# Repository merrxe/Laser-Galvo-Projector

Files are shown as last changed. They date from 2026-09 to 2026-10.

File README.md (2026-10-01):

# Лазерный проектор векторной графики на базе архитектуры ILDAWaveX16

## Цель проекта
Создать лазерный проектор векторной графики на основе готовых гальванометров (20 Kpps) и микроконтроллера ESP32-S3 по открытой архитектуре **ILDAWaveX16**, способный отображать векторные изображения и анимации на вертикальной поверхности с частотой обновления не менее 20 000 точек в секунду. Устройство должно поддерживать воспроизведение файлов стандартного лазерного формата `.ild`.

## Функционал
- Максимальная скорость рисования: не менее 20 000 точек/сек (20 Kpps).
- Угловое разрешение: не хуже 0.01° (при 16‑битном ЦАП).
- Размер проекционной области на расстоянии 2 м: не менее 1×1 м.
- Мощность лазера: до 100 мВт (класс 3R) с возможностью модернизации до 500 мВт (класс 3B) при обязательном использовании защитных очков.
- Длина волны: 532 нм (зелёный).
- Поддерживаемые форматы: `.ild` (стандарт ILDA), потоковые координаты по сети.
- Режимы работы:
  - *Онлайн* – ПК (скрипт Python) стримит координаты по Wi-Fi/Ethernet.
  - *Автономный* – воспроизведение сцен напрямую с microSD‑карты памяти.

## Задачи проекта
1. Закупка компонентов: гальванометры 20 Kpps с драйверами, микроконтроллер ESP32‑S3, ЦАП DAC80508, лазерный модуль 532 нм с TTL, ОУ LM324, компоненты обвязки питания.
2. 3D‑моделирование в Rhino 8 и печать корпуса с посадочными местами (материал PETG/ABS).
3. Лазерная резка передней и задней панелей из акрила 3 мм.
4. Разработка электрической схемы: связь ESP32‑S3 с DAC80508 по шине SPI, аналоговый каскад на ОУ LM324 для преобразования сигналов ЦАП в дифференциальный сигнал ±5 В для драйверов гальванометров, TTL‑управление лазером, подключение microSD-слота по выделенной шине SPI.
5. Программирование ESP32‑S3 (C++, PlatformIO):
   - Приём пакетов по UDP (сетевые протоколы IDN / IWP) в кольцевой буфер.
   - Синхронная генерация сигналов X/Y через ЦАП по аппаратному таймеру.
   - Управление TTL‑гашением с компенсацией задержки зеркал.
   - Чтение, парсинг и воспроизведение файлов `.ild` с карты памяти для автономной работы.
6. Разработка ПО для ПК (Python):
   - Математическая генерация тестовых паттернов и фигур.
   - Потоковая трансляция кадров на проектор по сети в реальном времени.
7. Сборка, калибровка и тестирование: юстировка, калибровка по сетке с автоматическим расчётом поправочных коэффициентов (линейная коррекция и устранение подушкообразных искажений), определение предельной частоты сканирования.

## Безопасность
- Аппаратный сторожевой таймер (Watchdog) на ESP32‑S3 – принудительно отключает лазер через TTL при прекращении поступления координат или зависании сетевого стека.
- Защита при сбое сканаторов – цепь контроля, блокирующая лазер при падении питания гальванометров или остановке зеркал в одной точке.

## Элементная база
- **Гальванометры**: комплект 20Kpps Galvo Scanner (2 гальванометра с зеркалами, 2 платы драйверов, БП ±15В/24В).
- **Микроконтроллер**: ESP32‑S3 (Dual-Core, поддержка аппаратного SPI и Wi-Fi).
- **ЦАП**: DAC80508 (16 бит, 8 каналов, SPI).
- **Аналоговый тракт**: ОУ LM324 для сдвига уровней и формирования дифференциального сигнала ±5 В. Интегрированный DC-DC повышающий конвертер для аналогового питания ±8 В от USB-C.
- **Лазер**: модуль 532 нм, 100 мВт со встроенным драйвером и TTL‑входом.
- **Хранение данных**: встроенный слот microSD-карт (шина SPI).
- **Конструкция**: пластик PETG/ABS для печати шасси, прозрачный/чёрный акрил 3 мм для панелей.

## Заключение
Разрабатываемый лазерный проектор на базе архитектуры ILDAWaveX16 сочетает высокую разрядность (16 бит), производительность (от 20 000 точек/сек) и современные сетевые интерфейсы. Проект соответствует международным базовым стандартам лазерной индустрии (ILDA), что существенно повышает его научно-практическую ценность.

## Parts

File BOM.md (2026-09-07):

# Список закупок (BOM)

| № | Наименование | Кол-во | Примечание | Ссылка для заказа |
|---|---|---|---|---|
| 1 | Комплект гальванометров 20Kpps Galvo Scanner | 1 компл. | Включает 2 гальванометра с зеркалами, 2 платы драйверов, импульсный БП 24 В | |
| 2 | Микроконтроллер ESP32-DevKitC V4 (на базе NodeMCU-32S) | 1 шт. | | |
| 3 | ЦАП MCP4922 (12 бит, 2 канала, SPI) | 1 шт. | | |
| 4 | Сдвоенный ОУ TL082 | 1 шт. | Для сдвига уровней 0…4 В → ±5 В | |
| 5 | Инвертирующий преобразователь ICL7660 (или аналог) | 1 шт. | Для получения –12 В из +12 В | |
| 6 | Лазерный модуль 532 нм, 100 мВт с TTL-входом | 1 шт. | Класс 3R, возможность замены на 500 мВт (класс 3B) | |
| 7 | Блок питания 12 В / 3 А | 1 шт. | Для ESP32, лазера, вентилятора | |
| 8 | Блок питания 24 В (из комплекта гальванометров) | 1 шт. | Входит в п.1 | |
| 9 | Пластик PLA или PETG для 3D-печати | ~1 кг | Для шасси | |
| 10 | Акриловый лист 3 мм (прозрачный/чёрный) | ~300×300 мм | Для передней/задней панелей | |
| 11 | Вентилятор 40×40 мм, 12 В | 1 шт. | Активное охлаждение | |
| 12 | Резисторы 100 Ом | 4 шт. | Для защиты выходов TL082 | |
| 13 | Концевой выключатель (механическая блокировка) | 1 шт. | Разрыв цепи питания лазера при открытии корпуса | |
| 14 | Провода, разъёмы, панельки, винты, стойки | по необходимости | Расходные материалы для монтажа | |

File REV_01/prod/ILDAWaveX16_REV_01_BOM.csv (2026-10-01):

Designator | Qty | MPN | Comment | Manufacturer | Footprint | Datasheet | JLCPCB Part #
U8 | 1 | DAC80508MRTE | DAC80508 | Texas Instruments | WQFN | https://www.ti.com/lit/ds/symlink/dac80508.pdf | C2679529
U7 | 1 | EMIF06-MSD02N16 | EMIF06-MSD02N16 | STMicroelectronics | Micro QFN 3.5x1.2-16L | https://www.st.com/resource/en/datasheet/emif06-msd02n16.pdf | C5267594
U6 | 1 | TLV61048DBV | TLV61048 | Texas Instruments | SOT-23-6 | https://www.ti.com/lit/ds/symlink/tlv61048.pdf | C2861467
U5 | 1 | TPS62160DSG | TPS62160 | Texas Instruments | WSON-8 (2x2mm) | https://datasheet.lcsc.com/lcsc/1806070425_Texas-Instruments-TPS62162DSGR_C40256.pdf | C324077
U4 | 1 | NCP167BMX330TBG | NCP167BMX330TBG | onsemi | XDFN-4 | https://datasheet.lcsc.com/lcsc/2107280040_onsemi-NCP167BMX330TBG_C892227.pdf | C892227
U3 | 1 | LM324QT | LM324QT | STMicroelectronics | QFN16 3x3 | https://www.lcsc.com/datasheet/lcsc_datasheet_1810010620_STMicroelectronics-LM324QT_C183029.pdf | C183029
U2 | 1 | USBLC6-2P6 | USBLC6-2P6 | STMicroelectronics | SOT666 | https://www.st.com/resource/en/datasheet/usblc6-2.pdf | C15999
U1 | 1 | ESP32-S3-MINI-1 | ESP32-S3-MINI-1 | Espressif Systems | Module | https://www.espressif.com/sites/default/files/documentation/esp32-s3-mini-1_mini-1u_datasheet_en.pdf | C2913206
SW1,SW2 | 2 | PTS810SJG250SMTRLFS | PTS810 | C&K | 3.2x2.5mm SMD | https://datasheet.lcsc.com/lcsc/1810121629_C-K-PTS810SJG250SMTRLFS_C221895.pdf | C221895
R20,R27,R28,R29,R30,R31,R32,R33,R34,R35,R36 | 11 | AC0402FR-07150RL | 150R | Yageo | 0402 | https://eu.mouser.com/datasheet/2/447/PYu-AC_51_RoHS_L_7-1714230.pdf | C226790
R19 | 1 | HP03W5F100KT5E | 1R | UNI-ROYAL | 0603 | https://www.lcsc.com/datasheet/lcsc_datasheet_2304140030_UNI-ROYAL-Uniroyal-Elec-HP03W5F100KT5E_C2759448.pdf | C2759448
R18 | 1 | 0402WGF1003TCE | 100k | UNI-ROYAL(Uniroyal Elec) | 0402 | https://datasheet.lcsc.com/szlcsc/1810111814_UNI-ROYAL-Uniroyal-Elec-0402WGF1003TCE_C25741.pdf | C25741
R15 | 1 | AC0402FR-07100RL | 100R | Yageo | 0402 | https://eu.mouser.com/datasheet/2/447/PYu-AC_51_RoHS_L_7-1714230.pdf | C144808
R14 | 1 | RK73G1ETTP1004F | 1M | KOA Speer Elec | 0402 | https://datasheet.lcsc.com/szlcsc/2004171812_KOA-Speer-Elec-RK73G1ETTP1004F_C516088.pdf | C516088
R10,R13,R23,R24 | 4 | RC0402FR-0720KL | 20k | YAGEO | 0402 | https://www.lcsc.com/datasheet/lcsc_datasheet_2304140030_YAGEO-RC0402FR-0720KL_C93942.pdf | C93942
R7 | 1 | RC0402FR-078K2L | 8.2k | Yageo | 0402 | https://www.lcsc.com/datasheet/lcsc_datasheet_2304140030_YAGEO-RC0402FR-078K2L_C137929.pdf | C137929
R6 | 1 | RC0402FR-0743KL | 43k | Yageo | 0402 | https://www.lcsc.com/datasheet/lcsc_datasheet_2304140030_YAGEO-RC0402FR-0743KL_C185415.pdf | C185415
R4,R5 | 2 | RC0402JR-0727RL | 27R | YAGEO | 0402 | https://datasheet.lcsc.com/szlcsc/1810241322_YAGEO-RC0402JR-0727RL_C137890.pdf | C137890
R2,R3 | 2 | AC0402FR-075K1L | 5.1k | YAGEO | 0402 | https://datasheet.lcsc.com/szlcsc/1810241326_YAGEO-AC0402FR-075K1L_C144745.pdf | C144745
R1,R8,R9,R11,R12,R16,R17,R21,R22,R25,R26 | 11 | RC0402FR-7W10KL | 10k | YAGEO | 0402 | https://datasheet.lcsc.com/lcsc/2104091834_YAGEO-RC0402FR-7W10KL_C851848.pdf | C851848
Q1 | 1 | AP3404 | AP3404 | ALLPOWER(ShenZhen Quan Li Semiconductor) | SOT-23 | https://datasheet.lcsc.com/lcsc/2202132030_ALLPOWER-ShenZhen-Quan-Li-Semiconductor-AP3404_C2842665.pdf | C2842665
L3 | 1 | XAL4030-472 | 4.7uH | Coilcraft | 4.0x4.0x3.1 | https://www.coilcraft.com/getmedia/6adcb47d-8b55-416c-976e-1e22e0d2848c/xal4000.pdf | C19191688
L2 | 1 | MPZ1608B471ATA00 | 470R | TDK | 0603 | https://www.lcsc.com/datasheet/lcsc_datasheet_1811131653_TDK-MPZ1608B471ATA00_C114780.pdf | C114780
L1 | 1 | VLCF4020T-2R2N1R7 | 2.2uH | TDK | 4x4x2mm | https://datasheet.lcsc.com/szlcsc/1810211523_TDK-VLCF4020T-2R2N1R7_C136245.pdf | C136245
J13 | 1 | 473521001 | 473521001 | Molex | SMD | https://www.molex.com/content/dam/molex/molex-dot-com/products/automated/en-us/salesdrawingpdf/473/47352/473521001_sd.pdf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 | C293569
J6,J7,J8,J9,J10,J11,J12 | 7 | B2B-XH-A(LF)(SN) | J_JST-XH-B2B | JST Sales America | Through Hole, P=2.5mm | http://www.jst-mfg.com/product/pdf/eng/eXH.pdf | C158012
J3,J4,J5 | 3 | B3B-XH-A(LF)(SN) | J_JST-XH-B3B | JST Sales America | Through Hole, P=2.5mm | http://www.jst-mfg.com/product/pdf/eng/eXH.pdf | C144394
J2 | 1 | X0325FT7B2 | X0325FT7B2 | XKB Connection | 25P | https://www.lcsc.com/datasheet/lcsc_datasheet_2307171038_XKB-Connection-X0325FT7B2_C7464461.pdf | C7464461
J1 | 1 | TYPE-C-31-M-14 | TYPE-C-31-M-14 | Korean Hroparts Elec | 16pin USB C | https://www.usb.org/sites/default/files/documents/usb_type-c.zip | C223907
F1,F2,F3 | 3 | SMD0805-050-16V | 0.5A | TECHFUSE | 0805 | https://www.lcsc.com/datasheet/lcsc_datasheet_2105241447_TECHFUSE-SMD0805-050-16V_C2833485.pdf | C2833485
D2,D3,D4,D5,D6,D7,D8 | 7 | 1N5819W | 1N5819W | TECH PUBLIC | SOD-123 | https://datasheet.lcsc.com/lcsc/2110200930_TECH-PUBLIC-1N5819W_C2905650.pdf | C2905650
D1 | 1 | XL-1010RGBC-WS2812B | XL-1010RGBC-WS2812B | XINGLIGHT | 1010 (1x1mm) | https://datasheet.lcsc.com/lcsc/2301111010_XINGLIGHT-XL-1010RGBC-WS2812B_C5349953.pdf | C5349953
C16,C17 | 2 | GRM188R61H225KE11D | 2.2uF | Murata Electronics | 0603 | https://datasheet.lcsc.com/lcsc/1912111437_Murata-Electronics-GRM188R61H225KE11D_C162273.pdf | C162273
C12 | 1 | CC1206KKX5R8BB106 | 10uF | YAGEO | 1210 | https://www.lcsc.com/datasheet/lcsc_datasheet_2407081117_YAGEO-CC1206KKX5R8BB106_C128855.pdf | C128855
C8,C9,C10,C11,C14,C15,C19,C20 | 8 | CL05A105KA5NQNC | 1uF | Samsung Electro-Mechanics | 0402 | https://datasheet.lcsc.com/szlcsc/1811091611_Samsung-Electro-Mechanics-CL05A105KA5NQNC_C52923.pdf | C52923
C6 | 1 | CL21A226MQQNNNF | 22uF | Samsung Electro-Mechanics | 0805 | https://datasheet.lcsc.com/lcsc/2304140030_Samsung-Electro-Mechanics-CL21A226MQQNNNF_C307531.pdf | C307531
C2 | 1 | CL21A106KAYNNNE | 10uF | Samsung Electro-Mechanics | 0805 | https://datasheet.lcsc.com/szlcsc/1811121310_Samsung-Electro-Mechanics-CL21A106KAYNNNE_C15850.pdf | C15850
C1,C3,C4,C5,C7,C13,C18 | 7 | CC0402KRX7R7BB104 | 100nF | Yageo | 0402 | https://www.yageo.com/upload/media/product/productsearch/datasheet/mlcc/UPY-GPHC_X7R_6.3V-to-50V_18.pdf | C60474

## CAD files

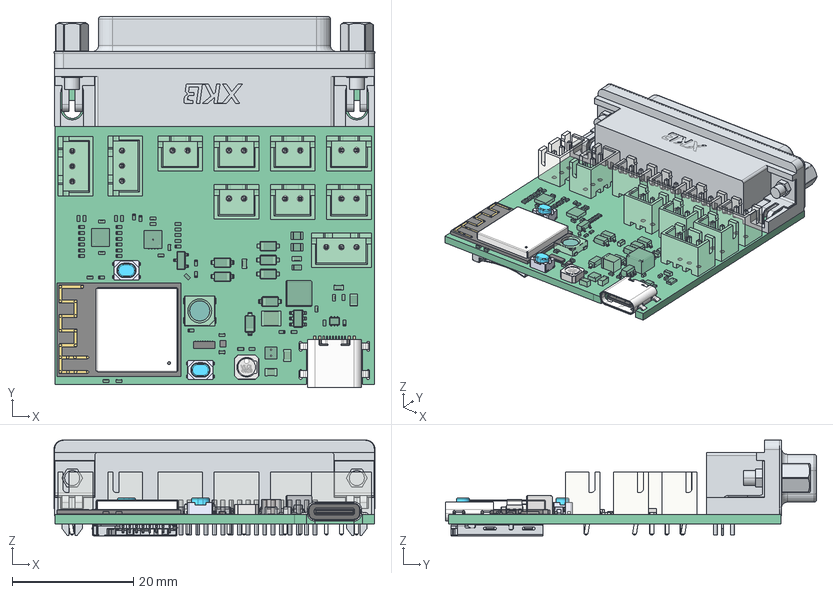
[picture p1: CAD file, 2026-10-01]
REV_01/prod/ILDAWaveX16_REV_01_3D.step
53.0 x 61.3 x 15.8 mm
Pcb_92e2
C9_C_0402_1005Metric_89ffe173dfdc
R5_R_0402_1005Metric_44aaff508362
R20_R_0402_1005Metric_53d4fa7b819a
D3_D_SOD-123_a8e0f4504b51
F3_Fuse_0805_2012Metric_754eb351aef8
D6_D_SOD-123_a57883263e1a
U3_QFN-16-1EP_3x3mm_P0.5mm_EP1.7x1.7mm_20b41260c2ea
R8_R_0402_1005Metric_efa2c0d2ec63
U8_QFN-16-1EP_3x3mm_P0.5mm_EP1.7x1.7mm_23e2c4e3b183
User Library-VLCF4020
User Library-VLCF4021
User Library-VLCF4022
User Library-VLCF4023
J4_JST_B3B_XH_A_536eab15d6f0
R28_R_0402_1005Metric_622625ac435b
R24_R_0402_1005Metric_195bccc64eb0
J12_JST_B2B_XH_A_ac59ba0f6e81
R26_R_0402_1005Metric_998ac3366432
R32_R_0402_1005Metric_e949ee6fe3ef
R10_R_0402_1005Metric_b8745a6824d8
J7_JST_B2B_XH_A_a2329b00c2bc
U5_WSON_8_1EP_2x2mm_P05mm_EP09x16mm_7ca23187abe5
D1_LED_SK6812_PLCC4_50x50mm_P32mm_a38316aae7d9
NCP160AMX280TBG
NCP160AMX280TBG001
NCP160AMX280TBG002
NCP160AMX280TBG003
NCP160AMX280TBG004
NCP160AMX280TBG005
C12_C_1210_3225Metric_b1d4a9e3416f
C1_C_0402_1005Metric_c4c7f1a68555
R31_R_0402_1005Metric_2ccf47463f8c
L2_L_0603_1608Metric_823896ec14eb
R25_R_0402_1005Metric_7808e2627087
C17_C_0603_1608Metric_f5fdf03a202d
C18_C_0402_1005Metric_2f88ed1da291
D5_D_SOD-123_01406cc71bf0
C15_C_0402_1005Metric_1636b44ef821
R34_R_0402_1005Metric_14bc605238ea
Shroud
Plastic Body & Connector
D7_D_SOD-123_fa214a08565a
R7_R_0402_1005Metric_2262573c13ee
D4_D_SOD-123_46b60e45f437
R4_R_0402_1005Metric_a4c3c69df47a
R15_R_0402_1005Metric_fdd16481b1f3
C14_C_0402_1005Metric_cdb5d3d3c35e
R27_R_0402_1005Metric_7878de1fa873
Q1_SOT-23_5085c68b8b23
C19_C_0402_1005Metric_107ad01726eb
C7_C_0402_1005Metric_4d52c1d3054a
C16_C_0603_1608Metric_b51fb48a76ba
D2_D_SOD-123_e067b67f9058
J6_JST_B2B_XH_A_f1e10dd8db81
C0201_20210301.STEP^C0201_20210301.STEP_Submodel-C0201_part_ DesignRootModel_ESP32-S3-MINI-1_V1(2)_ESP32-S3-MINI-1_V1 x 14
L0201_20210301.STEP^L0201_20210301.STEP_Submodel-L0201_part_ DesignRootModel_ESP32-S3-MINI-1_V1(2)_ESP32-S3-MINI-1_V1 x 3
R0201_20210301.STEP^R0201_20210301.STEP_Submodel-R0201_part_ DesignRootModel_ESP32-S3-MINI-1_V1(2)_ESP32-S3-MINI-1_V1 x 3
R0201_20210301.STEP^R0201_20210301.STEP_Submodel-R0201_part_ DesignRootModel_ESP32-S3-MINI-1_V1(2)_ESP32-S3-MINI-1_V002 x 3
R0201_20210301.STEP^R0201_20210301.STEP_Submodel-R0201_part_ DesignRootModel_ESP32-S3-MINI-1_V1(2)_ESP32-S3-MINI-1_V003 x 3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

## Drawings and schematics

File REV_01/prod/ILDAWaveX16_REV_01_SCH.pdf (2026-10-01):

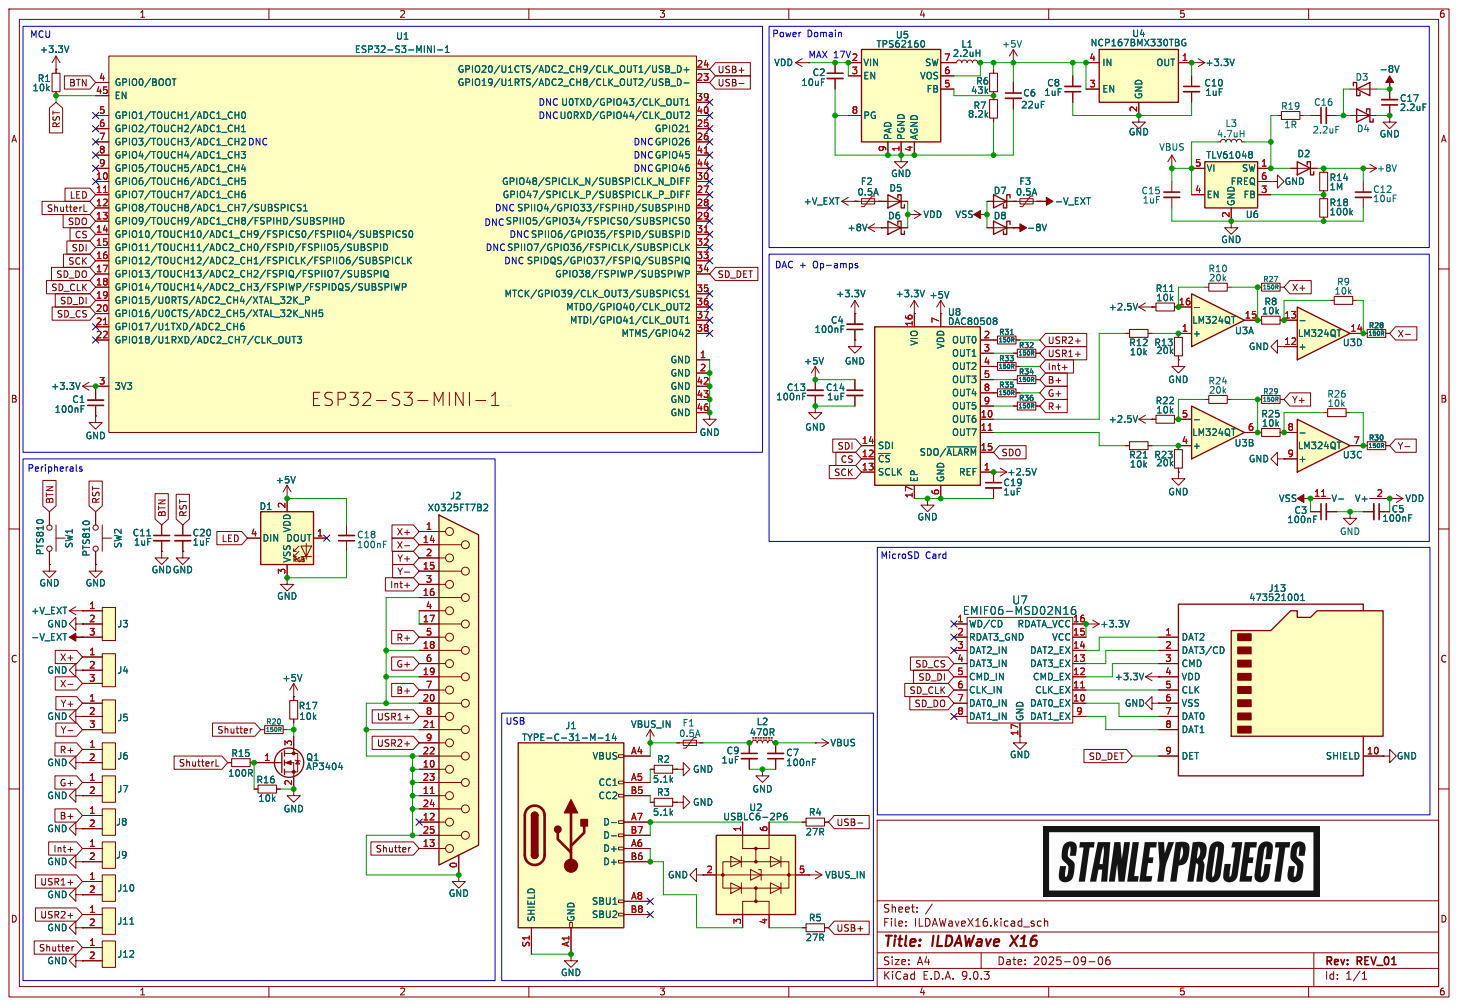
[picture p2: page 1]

DAC + Op-amps Power Domain USB

GPIO0/BOOT 4 EN 45 GPIO1/TOUCH1/ADC1_CH0 5 GPIO2/TOUCH2/ADC1_CH1 6 GPIO3/TOUCH3/ADC1_CH2 7 GPIO4/TOUCH4/ADC1_CH3 8 GPIO5/TOUCH5/ADC1_CH4 9 GPIO6/TOUCH6/ADC1_CH5 10 GPIO7/TOUCH7/ADC1_CH6 11 GPIO8/TOUCH8/ADC1_CH7/SUBSPICS1 12 GPIO9/TOUCH9/ADC1_CH8/FSPIHD/SUBSPIHD 13 GPIO10/TOUCH10/ADC1_CH9/FSPICS0/FSPIIO4/SUBSPICS0 14 GPIO11/TOUCH11/ADC2_CH0/FSPID/FSPIIO5/SUBSPID 15 GPIO12/TOUCH12/ADC2_CH1/FSPICLK/FSPIIO6/SUBSPICLK 16 GPIO13/TOUCH13/ADC2_CH2/FSPIQ/FSPIIO7/SUBSPIQ 17 GPIO14/TOUCH14/ADC2_CH3/FSPIWP/FSPIDQS/SUBSPIWP 18 GPIO15/U0RTS/ADC2_CH4/XTAL_32K_P 19 GPIO16/U0CTS/ADC2_CH5/XTAL_32K_NH5 20 GPIO17/U1TXD/ADC2_CH6 21 GPIO18/U1RXD/ADC2_CH7/CLK_OUT3 22

2 SW 1 FREQ 6 FB 3 GND

6 OUT0 2 OUT1 3 OUT2 4 OUT3 5 SDO/~{ALARM}15 REF 1 EP 17 OUT4 8 OUT5 9 OUT6 10 OUT7 11 U8 DAC80508 B+ Y+

6 OUT0 2 OUT1 3 OUT2 4 OUT3 5 SDO/~{ALARM}15 REF 1 EP 17 OUT4 8 OUT5 9 OUT6 10 OUT7 11 GND GND
10k GND

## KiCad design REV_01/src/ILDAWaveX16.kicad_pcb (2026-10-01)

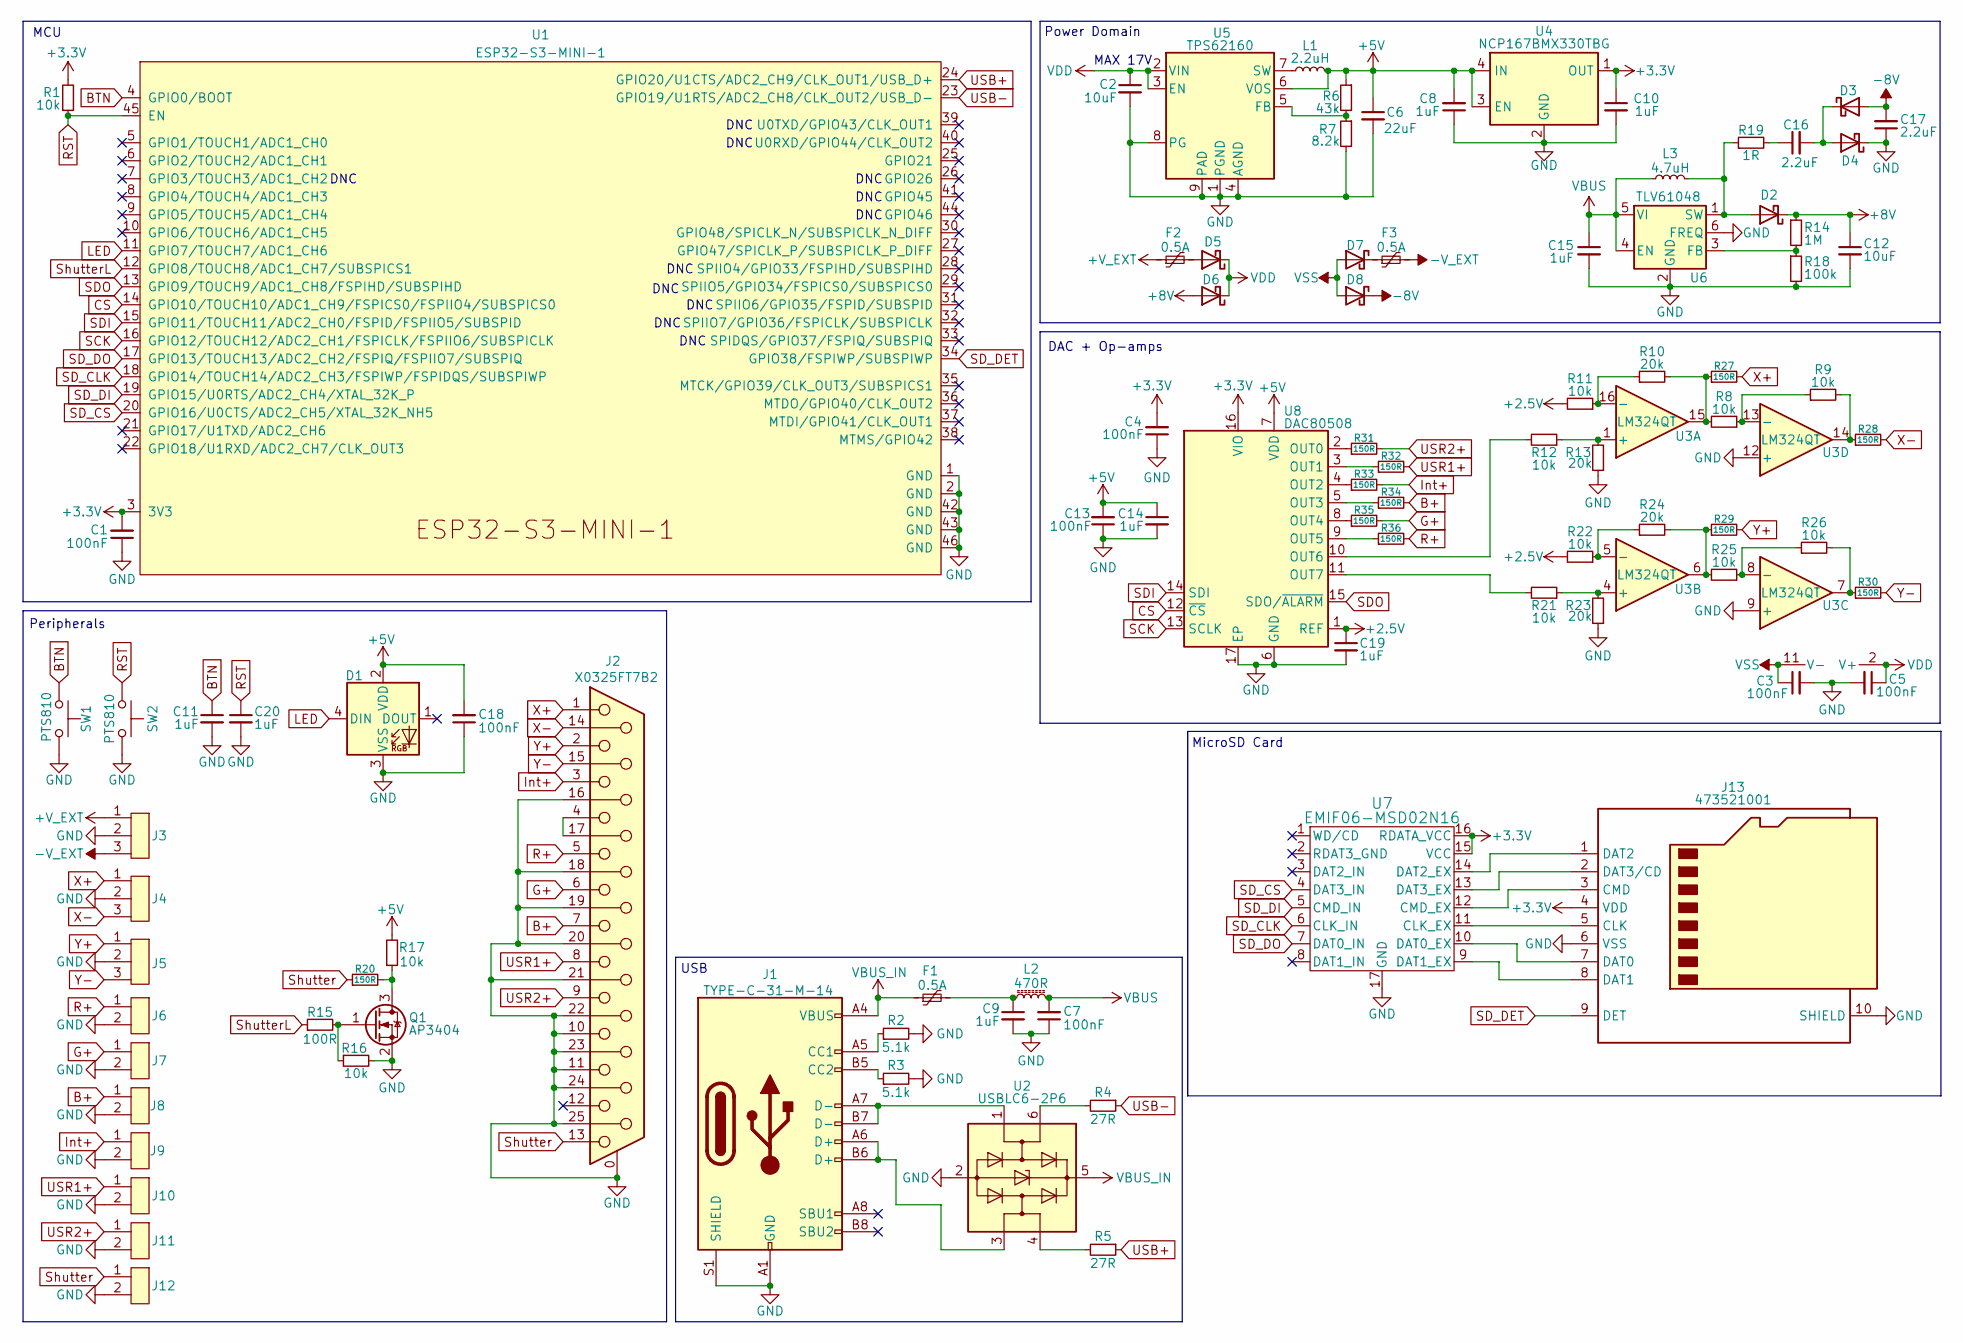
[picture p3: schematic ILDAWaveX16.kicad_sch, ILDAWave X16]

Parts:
C1, C3, C4, C5, C7, C13, C18: 100nF; C_0402_1005Metric; MPN CC0402KRX7R7BB104; LCSC# C60474
C2: 10uF; C_0805_2012Metric; MPN CL21A106KAYNNNE; LCSC# C15850
C6: 22uF; C_0805_2012Metric; MPN CL21A226MQQNNNF; LCSC# C307531
C8, C9, C10, C11, C14, C15, C19, C20: 1uF; C_0402_1005Metric; MPN CL05A105KA5NQNC; LCSC# C52923
C12: 10uF; C_1210_3225Metric; MPN CC1206KKX5R8BB106; LCSC# C128855
C16, C17: 2.2uF; C_0603_1608Metric; MPN GRM188R61H225KE11D; LCSC# C162273
D1: XL-1010RGBC-WS2812B; MPN XL-1010RGBC-WS2812B; LCSC# C5349953
D2, D3, D4, D5, D6, D7, D8: 1N5819W; D_SOD-123; MPN 1N5819W; LCSC# C2905650
F1, F2, F3: 0.5A; Fuse_0805_2012Metric; MPN SMD0805-050-16V; LCSC# C2833485
J1: TYPE-C-31-M-14; USB_C_Receptacle_HRO_TYPE-C-31-M-14; MPN TYPE-C-31-M-14; LCSC# C223907
J2: X0325FT7B2; J_DB25_Female_X0325FT7B2; MPN X0325FT7B2; LCSC# C7464461
J3, J4, J5: J_JST-XH-B3B; JST_XH_B3B-XH-A_1x03_P2.50mm_Vertical; MPN B3B-XH-A(LF)(SN); LCSC# C144394
J6, J7, J8, J9, J10, J11, J12: J_JST-XH-B2B; JST_XH_B2B-XH-A_1x02_P2.50mm_Vertical; MPN B2B-XH-A(LF)(SN); LCSC# C158012
J13: 473521001; microSD_HC_Molex_47352-1001; MPN 473521001; LCSC# C293569
L1: 2.2uH; VLCF4020; MPN VLCF4020T-2R2N1R7; LCSC# C136245
L2: 470R; L_0603_1608Metric; MPN MPZ1608B471ATA00; LCSC# C114780
L3: 4.7uH; L_Coilcraft_XAL4030-XXX; MPN XAL4030-472; LCSC# C19191688
Q1: AP3404; SOT-23; MPN AP3404; LCSC# C2842665
R1, R8, R9, R11, R12, R16, R17, R21, R22, R25, R26: 10k; R_0402_1005Metric; MPN RC0402FR-7W10KL; LCSC# C851848
R2, R3: 5.1k; R_0402_1005Metric; MPN AC0402FR-075K1L; LCSC# C144745
R4, R5: 27R; R_0402_1005Metric; MPN RC0402JR-0727RL; LCSC# C137890
R6: 43k; R_0402_1005Metric; MPN RC0402FR-0743KL; LCSC# C185415
R7: 8.2k; R_0402_1005Metric; MPN RC0402FR-078K2L; LCSC# C137929
R10, R13, R23, R24: 20k; R_0402_1005Metric; MPN RC0402FR-0720KL; LCSC# C93942
R14: 1M; R_0402_1005Metric; MPN RK73G1ETTP1004F; LCSC# C516088
R15: 100R; R_0402_1005Metric; MPN AC0402FR-07100RL; LCSC# C144808
R18: 100k; R_0402_1005Metric; MPN 0402WGF1003TCE; LCSC# C25741
R19: 1R; R_0603_1608Metric; MPN HP03W5F100KT5E; LCSC# C2759448
R20, R27, R28, R29, R30, R31, R32, R33, R34, R35, R36: 150R; R_0402_1005Metric; MPN AC0402FR-07150RL; LCSC# C226790
SW1, SW2: PTS810; SW_CK_PTS810; MPN PTS810SJG250SMTRLFS; LCSC# C221895
U1: ESP32-S3-MINI-1; MPN ESP32-S3-MINI-1; LCSC# C2913206
U2: USBLC6-2P6; SOT-666; MPN USBLC6-2P6; LCSC# C15999
U3: LM324QT; QFN-16-1EP_3x3mm_P0.5mm_EP1.7x1.7mm; MPN LM324QT; LCSC# C183029
U4: NCP167BMX330TBG; XDFN-4; MPN NCP167BMX330TBG; LCSC# C892227
U5: TPS62160; WSON-8-1EP_2x2mm_P0.5mm_EP0.9x1.6mm_ThermalVias; MPN TPS62160DSG; LCSC# C324077
U6: TLV61048; SOT-23-6; MPN TLV61048DBV; LCSC# C2861467
U7: EMIF06-MSD02N16; MICROQFN16_1P25X3P55X0P4_STM; MPN EMIF06-MSD02N16; LCSC# C5267594
U8: DAC80508; Texas_RTE0016D_WQFN-16-1EP_3x3mm_P0.5mm_EP0.8x0.8mm_Thermal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; MPN DAC80508MRTE; LCSC# C2679529

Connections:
+2.5V: C19.1, R11.2, R22.2, U8.1 (REF)
+3.3V: C1.2, C4.2, C10.1, J13.4 (VDD), R1.2, U1.3 (3V3), U4.1 (OUT), U7.15 (VCC), U7.16 (RDATA_VCC), U8.16 (VIO)
+5V: C6.1, C8.2, C13.2, C14.1, C18.2, D1.2 (VDD), L1.2, R6.1, R17.2, U4.3 (EN), U4.4 (IN), U5.6 (VOS), U8.7 (VDD)
+8V: C12.1, D2.1 (K), D6.2 (A), R14.1
+V_EXT: F2.1, J3.1
-8V: C17.2, D3.2 (A), D8.1 (K)
-V_EXT: F3.2, J3.3
B+: J2.7, J8.1, R34.2
BTN: C11.1, SW1.1, SW1.2, U1.4 (GPIO0/BOOT)
CS: U1.14 (GPIO10/TOUCH10/ADC1_CH9/FSPICS0/FSPIIO4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), U8.12 (~CS)
G+: J2.6, J7.1, R35.2
GND: C1.1, C2.2, C3.2, C4.1, C5.2, C6.2, C7.1, C8.1, C9.2, C10.2, C11.2, C12.2, C13.1, C14.2, C15.2, C17.1, C18.1, C19.2, C20.2, D1.3 (VSS), D4.1 (K), J1.A1 (GND), J1.A12 (GND), J1.B1 (GND), J1.B12 (GND), J1.S1 (SHIELD), J2.0 (PAD), J2.10, J2.11, J2.16, J2.18, J2.19, J2.20, J2.21, J2.22, J2.23, J2.24, J2.25, J3.2, J4.2, J5.2, J6.2, J7.2, J8.2, J9.2, J10.2, J11.2, J12.2, J13.6 (VSS), J13.10 (SHIELD), Q1.2 (S), R2.2, R3.2, R7.2, R13.1, R16.2, R18.2, R23.1, SW1.3, SW1.4, SW2.3, SW2.4, U1.1 (GND), U1.2 (GND), U1.42 (GND), U1.43 (GND), U1.46 (GND), U2.2 (GND), U3.9 (+), U3.12 (+), U4.2 (GND), U4.5 (GND), U5.1 (PGND), U5.4 (AGND), U5.8 (PG), U5.9 (PAD), U6.2 (GND), U6.6 (FREQ), U7.17 (GND), U8.6 (GND), U8.17 (EP)
Int+: J2.3, J9.1, R33.2
LED: D1.4 (DIN), U1.11 (GPIO7/TOUCH7/ADC1_CH6)
unnamed: C9.1, F1.2, L2.1
unnamed: C16.1, R19.2
unnamed: D2.2 (A), L3.1, R19.1, U6.1 (SW)
unnamed: C16.2, D3.1 (K), D4.2 (A)
unnamed: D5.2 (A), F2.2
unnamed: D7.1 (K), F3.1
unnamed: J1.A5 (CC1), R2.1
unnamed: J1.B5 (CC2), R3.1
unnamed: J1.A6 (D+), J1.B6 (D+), U2.3 (I/O2)
unnamed: J1.A7 (D-), J1.B7 (D-), U2.1 (I/O1)
unnamed: J2.4, J2.17
unnamed: J13.5 (CLK), U7.11 (CLK_EX)
unnamed: J13.3 (CMD), U7.12 (CMD_EX)
unnamed: J13.7 (DAT0), U7.10 (DAT0_EX)
unnamed: J13.8 (DAT1), U7.9 (DAT1_EX)
unnamed: J13.1 (DAT2), U7.14 (DAT2_EX)
unnamed: J13.2 (DAT3/CD), U7.13 (DAT3_EX)
unnamed: Q1.3 (D), R17.1, R20.2
unnamed: Q1.1 (G), R15.2, R16.1
unnamed: R4.2, U2.6 (I/O1)
unnamed: R5.2, U2.4 (I/O2)
unnamed: R8.2, R10.2, R27.1, U3.15
unnamed: R24.2, R25.2, R29.1, U3.6
unnamed: R26.2, R30.1, U3.7
unnamed: R9.2, R28.1, U3.14
unnamed: R12.1, R13.2, U3.1 (+)
unnamed: R10.1, R11.1, U3.16 (-)
unnamed: R21.1, R23.2, U3.4 (+)
unnamed: R22.1, R24.1, U3.5 (-)
unnamed: R25.1, R26.1, U3.8 (-)
unnamed: R8.1, R9.1, U3.13 (-)
unnamed: R6.2, R7.1, U5.5 (FB)
unnamed: L1.1, U5.7 (SW)
unnamed: R14.2, R18.1, U6.3 (FB)
unnamed: R31.1, U8.2 (OUT0)
unnamed: R32.1, U8.3 (OUT1)
unnamed: R33.1, U8.4 (OUT2)
unnamed: R34.1, U8.5 (OUT3)
unnamed: R35.1, U8.8 (OUT4)
unnamed: R36.1, U8.9 (OUT5)
unnamed: R12.2, U8.10 (OUT6)
unnamed: R21.2, U8.11 (OUT7)
R+: J2.5, J6.1, R36.2
RST: C20.1, R1.1, SW2.1, SW2.2, U1.45 (EN)
SCK: U1.16 (GPIO12/TOUCH12/ADC2_CH1/FSPICLK/FSPIIO6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), U8.13 (SCLK)
SDI: U1.15 (GPIO11/TOUCH11/ADC2_CH0/FSPID/FSPIIO5/S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), U8.14 (SDI)
SDO: U1.13 (GPIO9/TOUCH9/ADC1_CH8/FSPIHD/SUBSPIHD), U8.15 (SDO/~ALARM)
SD_CLK: U1.18 (GPIO14/TOUCH14/ADC2_CH3/FSPIWP/FSPIDQS/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), U7.6 (CLK_IN)
SD_CS: U1.20 (GPIO16/U0CTS/ADC2_CH5/XTAL_32K_NH5), U7.4 (DAT3_IN)
SD_DET: J13.9 (DET), U1.34 (GPIO38/FSPIWP/SUBSPIWP)
SD_DI: U1.19 (GPIO15/U0RTS/ADC2_CH4/XTAL_32K_P), U7.5 (CMD_IN)
SD_DO: U1.17 (GPIO13/TOUCH13/ADC2_CH2/FSPIQ/FSPIIO7/S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), U7.7 (DAT0_IN)
Shutter: J2.13, J12.1, R20.1
ShutterL: R15.1, U1.12 (GPIO8/TOUCH8/ADC1_CH7/SUBSPICS1)
USB+: R5.1, U1.24 (GPIO20/U1CTS/ADC2_CH9/CLK_OUT1/USB_D+)
USB-: R4.1, U1.23 (GPIO19/U1RTS/ADC2_CH8/CLK_OUT2/USB_D-)
USR1+: J2.8, J10.1, R32.2
USR2+: J2.9, J11.1, R31.2
VBUS: C7.2, C15.1, L2.2, L3.2, U6.4 (EN), U6.5 (VI)
VBUS_IN: F1.1, J1.A4 (VBUS), J1.A9 (VBUS), J1.B4 (VBUS), J1.B9 (VBUS), U2.5 (VBUS)
VDD: C2.1, C5.1, D5.1 (K), D6.1 (K), U3.2 (V+), U5.2 (VIN), U5.3 (EN)
VSS: C3.1, D7.2 (A), D8.2 (A), U3.11 (V-)
X+: J2.1, J4.1, R27.2
X-: J2.14, J4.3, R28.2
Y+: J2.2, J5.1, R29.2
Y-: J2.15, J5.3, R30.2

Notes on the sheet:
USB
DNC
MAX 17V
MCU
MicroSD Card
Power Domain
Peripherals
DAC + Op-amps

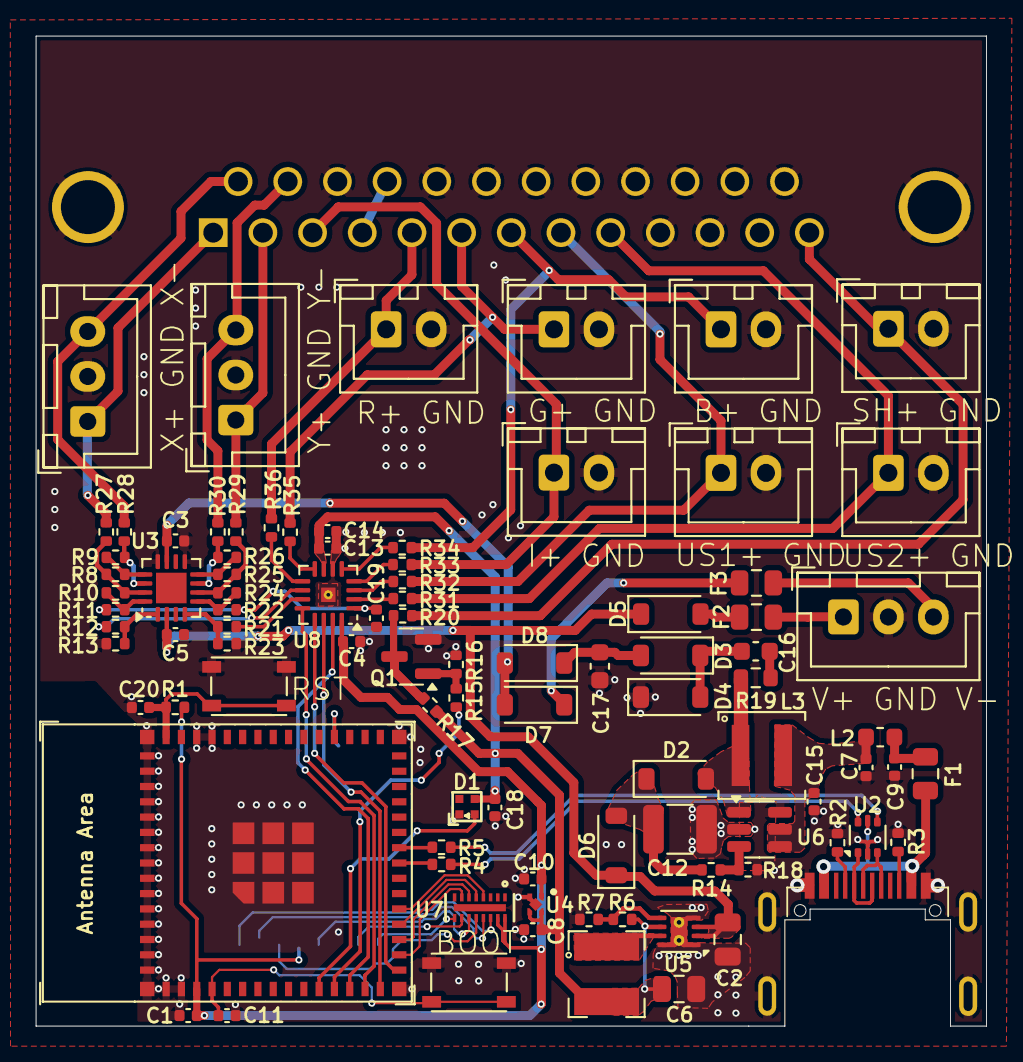
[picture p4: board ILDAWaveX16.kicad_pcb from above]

Board: 2 copper layers, 52.8 x 55.0 mm, 94 parts (1 on the bottom side), 80 nets.

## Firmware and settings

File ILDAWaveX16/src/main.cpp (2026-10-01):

#include <Arduino.h> 
#include <vector>
#include <Adafruit_NeoPixel.h>
#include <SDCard.h>
#include <Renderer.h>
#include <IDNServer.h>
#include <IWPServer.h>
#include <WiFi.h>
#include "esp_wifi.h"
#include <AsyncTCP.h>
#include <ESPAsyncWebServer.h>
#include "driver/timer.h"
#include <Preferences.h>
#include "esp_task_wdt.h"
#include "wifi_credentials.h"
#include <ESPmDNS.h>
#include <ElegantOTA.h>
#include "esp_ota_ops.h"

using namespace std;

// Serial buffer for web interface - circular buffer to prevent memory fragmentation
char serialBuffer[3000];
int serialHead = 0;
int serialSize = 0;
const int MAX_SERIAL_BUFFER = 3000;

Preferences preferences;
Adafruit_NeoPixel pixels(1, PIN_LED, NEO_GRB + NEO_KHZ800);
SDCard sd;
Renderer renderer;
AsyncWebServer server(80);
File current_file;

IDNServer idn;
IWPServer iwp;

String currentlyPlayingFile = "";

// Function to add text to serial buffer for web display
void addToSerialBuffer(String text) {
  for (int i = 0; i < text.length(); i++) {
    serialBuffer[serialHead] = text[i];
    serialHead = (serialHead + 1) % MAX_SERIAL_BUFFER;
    if (serialSize < MAX_SERIAL_BUFFER) {
      serialSize++;
    }
  }
}

// Function to get serial buffer as String for web interface
String getSerialBuffer() {
  String result = "";
  result.reserve(serialSize + 1);

  if (serialSize < MAX_SERIAL_BUFFER) {
    // Buffer not full yet, read from beginning
    for (int i = 0; i < serialSize; i++) {
      result += serialBuffer[i];
    }
  } else {
    // Buffer is full, read from head to end, then from beginning to head
    for (int i = serialHead; i < MAX_SERIAL_BUFFER; i++) {
      result += serialBuffer[i];
    }
    for (int i = 0; i < serialHead; i++) {
      result += serialBuffer[i];
    }
  }
  return result;
}

// Custom print functions that also store in buffer
void webSerial(String text) {
  Serial.print(text);
  addToSerialBuffer(text);
}

void webSerialln(String text) {
  Serial.println(text);
  addToSerialBuffer(text + "\n");
}

void init_wifi() {
  String ssid;
  String password;
  String mdns_name;

  preferences.begin("app", false);
  ssid = preferences.getString("ssid", "");
  password = preferences.getString("password", "");
  mdns_name = preferences.getString("mdns_name", "ildawavex16");
  preferences.end();

  if (ssid == "" || password == ""){
    ssid = WIFI_SSID;
    password = WIFI_PASSWORD;
  }

  WiFi.mode(WIFI_AP_STA);

  WiFi.softAP("ILDAWaveX16", "ildawave");
  webSerial("AP IP address: ");
  webSerialln(WiFi.softAPIP().toString());

  WiFi.begin(ssid, password);
  webSerial("Connecting to WiFi");

  uint8_t attempts = 0;
  while (WiFi.status() != WL_CONNECTED && attempts < 20) {
      delay(500);
      webSerial(".");
      attempts++;
  }
  if (WiFi.status() == WL_CONNECTED) {
    webSerial("\nLocal IP: ");
    webSerialln(WiFi.localIP().toString());

    // Start mDNS service
    if (MDNS.begin(mdns_name.c_str())) {
      webSerial("mDNS responder started: ");
      webSerial(mdns_name);
      webSerialln(".local");
      MDNS.addService("http", "tcp", 80);
    } else {
      webSerialln("Error starting mDNS");
    }
  }
  else webSerialln("\nWiFi Connection Failed!");
}

const char index_html[] PROGMEM = R"rawliteral(
<!DOCTYPE html>
<html>
<head>
<meta charset="UTF-8">
<meta name="viewport" content="width=device-width,initial-scale=1">
<title>SD Player</title>
<style>
*{box-sizing:border-box}:root{--bg:#1a1a1f;--surface:#252530;--primary:#32323f;--accent:#4a9eff;--text:#e8e8ec;--text-dim:#8888a0;--border:#3a3a48;--radius:0.5em}html,body{margin:0;padding:0;min-height:100%}body{font-family:system-ui,-apple-system,sans-serif;background:var(--bg);color:var(--text);line-height:1.5}main{max-width:60em;margin:0 auto;padding:1em}h2{text-align:center;margin:.5em 0 0;font-size:1.5em;background:linear-gradient(90deg,red,#ff8000,#ff0,#0f0,#0ff,#0080ff,#8000ff,#ff0080,red);background-size:200% 100%;-webkit-background-clip:text;background-clip:text;color:transparent;animation:r 3s linear infinite}@keyframes r{to{background-position:200% 50%}}.card{background:var(--surface);border-radius:var(--radius);padding:1em;margin-bottom:1em}.card-title{font-weight:600;margin-bottom:.75em;padding-bottom:.5em;border-bottom:1px solid var(--border);display:flex;align-items:center;gap:.5em}#tableContainer{max-height:12em;overflow-y:auto;border-radius:var(--radius);background:var(--primary)}table{width:100%;border-collapse:collapse}th,td{padding:.6em .8em;text-align:left}th{background:var(--bg);position:sticky;top:0;font-size:.85em;text-transform:uppercase;color:var(--text-dim)}tr:not(:last-child) td{border-bottom:1px solid var(--border)}tr:hover td{background:rgba(74,158,255,.1)}tr.selected td{background:rgba(74,158,255,.25)}.btn-row{display:flex;gap:.5em;margin-top:1em;flex-wrap:wrap}button{flex:1;min-width:6em;padding:.75em 1em;border:none;border-radius:var(--radius);background:var(--primary);color:var(--text);font-size:1em;cursor:pointer;transition:background .2s,transform .1s}button:hover{background:var(--accent)}button:active{transform:scale(.97)}.control-group{margin-bottom:1em}.control-group:last-child{margin-bottom:0}.control-label{display:flex;justify-content:space-between;margin-bottom:.3em;font-size:.9em}.control-value{color:var(--accent);font-weight:600}input[type=range]{width:100%;height:.4em;border-radius:.2em;background:var(--primary);outline:none;-webkit-appearance:none}input[type=range]::-webkit-slider-thumb{-webkit-appearance:none;width:1.2em;height:1.2em;border-radius:50%;background:var(--accent);cursor:pointer}input[type=range]::-moz-range-thumb{width:1.2em;height:1.2em;border-radius:50%;background:var(--accent);cursor:pointer;border:none}.input-group{display:flex;flex-direction:column;gap:.5em}input[type=text]{width:100%;padding:.7em;border:1px solid var(--border);border-radius:var(--radius);background:var(--primary);color:var(--text);font-size:1em;transition:border-color .2s}input[type=text]:focus{outline:2px solid var(--accent);outline-offset:-2px}input[type=text]::placeholder{color:var(--text-dim)}input[type=text].invalid{border-color:#ff4444}input[type=text].valid{border-color:#44ff44}button:disabled{opacity:0.6;cursor:not-allowed}footer{text-align:center;padding:1em;color:var(--text-dim);font-size:.8em}@media(max-width:30em){main{padding:.5em}.card{padding:.8em}th,td{padding:.5em;font-size:.9em}}
</style>
</head>
<body>
<main>
<h2>&#9889; ILDAWaveX16 &#9889;</h2>
<div id="deviceInfo" style="text-align:center;margin-bottom:1em;padding:0.5em;font-size:0.85em;color:var(--text-dim);">
<div>IP: <span id="deviceIP">Loading...</span> | mDNS: <span id="deviceMDNS">Loading...</span>.local</div>
</div>
<div id="nowPlaying" style="display:none;text-align:center;margin-bottom:1em;padding:0.75em;background:linear-gradient(90deg,var(--accent),var(--primary));border-radius:var(--radius);font-weight:600;">
<div>&#9654; Now Playing: <span id="currentFile"></span></div>
</div>
<div class="card">
<div class="card-title">&#128194; SD Card</div>
<div id="tableContainer">
<table id="fileTable"><tr><th>Filename</th><th>Size</th></tr><!-- FILE_ROWS --></table>
</div>
<div class="btn-row">
<button onclick="playFile()">&#9654; Play</button>
<button onclick="stopFile()">&#9209; Stop</button>
</div>
</div>
<div class="card">
<div class="card-title">&#9881; Projection Settings</div>
<div class="control-group">
<div class="control-label"><span>Scan Period</span><span class="control-value"><span id="rateValue">10</span> &micro;s</span></div>
<input type="range" id="scanRate" min="10" max="10000" value="10" oninput="updateSettings()">
</div>
<div class="control-group">
<div class="control-label"><span>Brightness</span><span class="control-value"><span id="brightnessValue">100</span>%</span></div>
<input type="range" id="brightness" min="0" max="100" value="100" oninput="updateSettings()">
</div>
</div>
<div class="card">
<div class="card-title" style="cursor:pointer;" onclick="toggleSettings()">&#9881; Settings <span id="settingsToggle">&#9660;</span></div>
<div id="settingsContainer">
<div style="padding:1em;">
<div style="font-weight:600;margin-bottom:0.75em;padding-bottom:0.5em;border-bottom:1px solid var(--border);display:flex;align-items:center;gap:0.5em;">&#128246; Wi-Fi Settings</div>
<div class="input-group">
<input type="text" id="ssid" placeholder="SSID">
<input type="text" id="pass" placeholder="Password">
<button onclick="setWiFi()">Save &amp; Connect</button>
</div>
</div>
<div style="padding:1em;">
<div style="font-weight:600;margin-bottom:0.75em;padding-bottom:0.5em;border-bottom:1px solid var(--border);display:flex;align-items:center;gap:0.5em;">&#127760; Network Name - DNS</div>
<div class="input-group">
<div style="display:flex;align-items:center;gap:0.5em;margin-bottom:0.5em;">
<input type="text" id="mdns_name" placeholder="e.g. laser1" style="flex:1;">
<span style="color:var(--text-dim);font-size:0.9em;">.local</span>
</div>
<button onclick="setMDNS()">Save & Restart</button>
</div>
</div>
<div style="padding:1em;">
<div style="cursor:pointer;font-weight:600;margin-bottom:0.75em;padding-bottom:0.5em;border-bottom:1px solid var(--border);display:flex;align-items:center;gap:0.5em;" onclick="toggleSerial()">&#128196; Serial Monitor <span id="serialToggle">&#9660;</span></div>
<div id="serialContainer">
<div id="serialOutput" style="height:12em;overflow-y:auto;background:var(--primary);border-radius:var(--radius);padding:0.75em;font-family:monospace;font-size:0.85em;line-height:1.2em;white-space:pre-wrap;border:1px solid var(--border);"></div>
<div class="btn-row">
<button onclick="clearSerial()">Clear</button>
<button onclick="toggleAutoUpdate()" id="autoUpdateBtn">Auto-update: ON</button>
</div>
</div>
</div>
<div style="padding:1em;">
<div class="btn-row">
<button onclick="window.open('/update', '_blank')">&#8593; OTA Update</button>
</div>
</div>
</div>
</div>
</main>
<footer><a href="https://stanleyprojects.com/" style="color:inherit;text-decoration:none" target="_blank" rel="noopener noreferrer">StanleyProjects</a> | VER 0.2</footer>
<script>
let s=null,autoUpdate=true,updateInterval;

document.addEventListener("DOMContentLoaded",()=>{
  document.querySelectorAll("#fileTable tr").forEach((r,i)=>{
    if(!i)return;
    r.onclick=()=>{
      document.querySelectorAll("#fileTable tr").forEach(x=>x.classList.remove("selected"));
      r.classList.add("selected");
      s=r.dataset.filename
    };
    r.ondblclick=()=>{s=r.dataset.filename;playFile()}
  });
  startSerialUpdate();
  loadMDNSName();
  loadDeviceInfo();
  setInterval(loadDeviceInfo, 5000)
});

function loadMDNSName(){
  fetch("/get_mdns").then(r=>r.text()).then(name=>{
    document.getElementById("mdns_name").value=name
  }).catch(console.error)
}

function loadDeviceInfo(){
  fetch("/get_device_info").then(r=>r.json()).then(data=>{
    document.getElementById("deviceIP").textContent=data.ip;
    document.getElementById("deviceMDNS").textContent=data.mdns;

    const nowPlaying=document.getElementById("nowPlaying");
    const currentFile=document.getElementById("currentFile");

    if(data.playing){
      currentFile.textContent=data.playing;
      nowPlaying.style.display="block"
    }else{
      nowPlaying.style.display="none"
    }
  }).catch(console.error)
}

function playFile(){
  if(!s){alert("Select a file.");return}
  fetch(`/play?file=${encodeURIComponent(s)}&rate=${document.getElementById("scanRate").value}`).then(()=>loadDeviceInfo())
}

function stopFile(){
  fetch("/stop").then(()=>loadDeviceInfo())
}

function updateSettings(){
  const r=document.getElementById("scanRate"),b=document.getElementById("brightness");
  document.getElementById("rateValue").textContent=r.value;
  document.getElementById("brightnessValue").textContent=b.value;
  fetch(`/control?rate=${r.value}&brightness=${b.value}`).catch(console.error)
}

function validateInput(input,isValid){
  input.classList.remove("valid","invalid");
  input.classList.add(isValid?"valid":"invalid");
  return isValid
}

function setWiFi(){
  const ssidInput=document.getElementById("ssid");
  const passInput=document.getElementById("pass");

  const ssidValid=validateInput(ssidInput,ssidInput.value.length>0);
  const passValid=validateInput(passInput,passInput.value.length>=8||passInput.value.length===0);

  if(!ssidValid){
    alert("SSID cannot be empty");
    return
  }
  if(!passValid){
    alert("Password must be at least 8 characters or empty for open network");
    return
  }

  const btn=event.target;
  const originalText=btn.textContent;
  btn.textContent="Saving...";
  btn.disabled=true;

  fetch(`/set_wifi?ssid=${encodeURIComponent(ssidInput.value)}&pass=${encodeURIComponent(passInput.value)}`)
    .then(()=>{
      btn.textContent="WiFi Updated!";
      setTimeout(()=>{btn.textContent=originalText;btn.disabled=false},3000)
    })
    .catch((err)=>{
      // Connection reset is expected during restart - treat as success
      if(err.message.includes("fetch")||err.message.includes("Failed")){
        btn.textContent="WiFi Updated!";
        setTimeout(()=>{btn.textContent=originalText;btn.disabled=false},3000)
      }else{
        btn.textContent="Error!";
        setTimeout(()=>{btn.textContent=originalText;btn.disabled=false},2000)
      }
    })
}

function setMDNS(){
  const mdnsInput=document.getElementById("mdns_name");
  const mdnsRegex=/^[a-z0-9]([a-z0-9-]*[a-z0-9])?$/i;

  const mdnsValid=validateInput(mdnsInput,mdnsInput.value.length>0&&mdnsInput.value.length<=63&&mdnsRegex.test(mdnsInput.value));

  if(!mdnsValid){
    alert("mDNS name must be 1-63 characters, alphanumeric with hyphens (not starting/ending with hyphen)");
    return
  }

  const btn=event.target;
  const originalText=btn.textContent;
  btn.textContent="Saving...";
  btn.disabled=true;

  const newName=mdnsInput.value;

  fetch(`/set_mdns?name=${encodeURIComponent(newName)}`)
    .then(()=>{
      btn.textContent="mDNS Updated!";
      setTimeout(()=>{
        btn.textContent="Redirecting...";
        window.location.href=`http://${newName}.local/`
      },1000)
    })
    .catch((err)=>{
      // Connection reset is expected during restart - treat as success
      if(err.message.includes("fetch")||err.message.includes("Failed")){
        btn.textContent="mDNS Updated!";
        setTimeout(()=>{
          btn.textContent="Redirecting...";
          window.location.href=`http://${newName}.local/`
        },2000)
      }else{
        btn.textContent="Error!";
        setTimeout(()=>{btn.textContent=originalText;btn.disabled=false},2000)
      }
    })
}

function updateSerial(){
  fetch("/serial").then(r=>r.text()).then(data=>{
    const out=document.getElementById("serialOutput");
    const wasAtBottom=out.scrollTop>=out.scrollHeight-out.clientHeight-5;
    out.textContent=data;
    if(wasAtBottom)out.scrollTop=out.scrollHeight
  }).catch(console.error)
}

function clearSerial(){
  fetch("/clear_serial");
  document.getElementById("serialOutput").textContent=""
}

function toggleAutoUpdate(){
  autoUpdate=!autoUpdate;
  document.getElementById("autoUpdateBtn").textContent=`Auto-update: ${autoUpdate?"ON":"OFF"}`;
  if(autoUpdate)startSerialUpdate();else clearInterval(updateInterval)
}

function toggleSettings(){
  const container=document.getElementById("settingsContainer");
  const toggle=document.getElementById("settingsToggle");

  if(container.style.display==="none"){
    container.style.display="block";
    toggle.textContent="▼"
  }else{
    container.style.display="none";
    toggle.textContent="▶"
  }
}

function toggleSerial(){
  const container=document.getElementById("serialContainer");
  const toggle=document.getElementById("serialToggle");

  if(container.style.display==="none"){
    container.style.display="block";
    toggle.textContent="▼"
  }else{
    container.style.display="none";
    toggle.textContent="▶"
  }
}

function startSerialUpdate(){
  updateSerial();
  updateInterval=setInterval(updateSerial,1000)
}

function waitForReboot(){
  fetch("/ota_status").then(()=>{
    location.reload()
  }).catch(()=>{
    setTimeout(waitForReboot,2000)
  })
}

// Monitor for OTA updates by checking if update page is opened
setInterval(()=>{
  if(document.hidden)return;
  fetch("/ota_status").catch(()=>{
    console.log("Device may be rebooting...");
    waitForReboot()
  })
},5000)
</script>
</body>
</html>
)rawliteral";
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
void loop(){ vTaskDelete(NULL); }
